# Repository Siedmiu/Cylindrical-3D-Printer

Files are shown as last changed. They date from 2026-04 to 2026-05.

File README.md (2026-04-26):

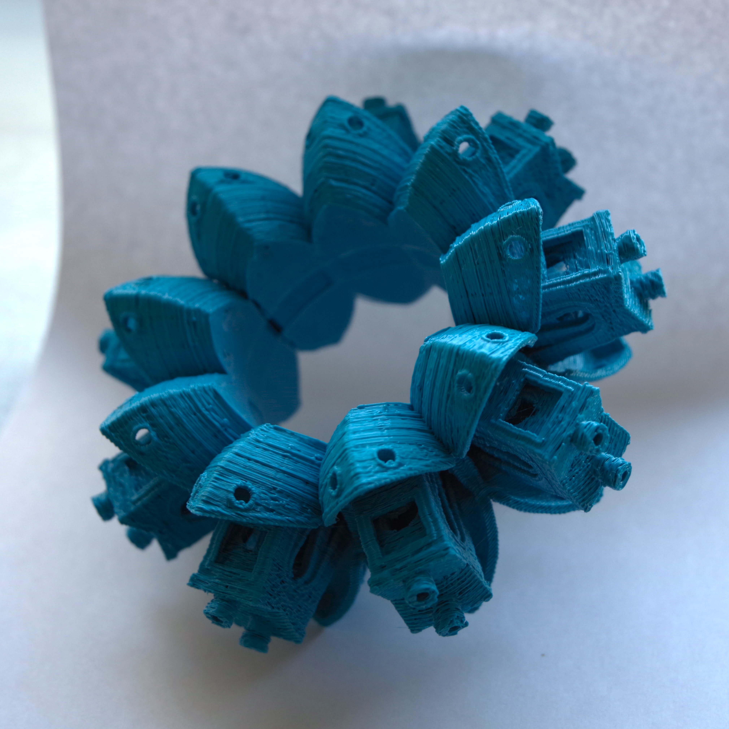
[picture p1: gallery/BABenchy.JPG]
Cylindrical 3D Printer

<sub>Yes, I had a nozzle clog while printing this...</sub>

# Cylindrical 3D Printer

An open-source cylindrical (polar) 3D printer built from raw components and 3D printed parts. Instead of a flat print bed, the model is deposited onto a rotating drum — enabling geometries that are impossible or impractical on a standard Cartesian FDM printer, such as seamless cylindrical shells and radially symmetric structures.

The printer runs **Marlin 2.1** with POLAR kinematics on a **BTT SKR V1.4 Turbo** board. Two independent methods for generating G-code are provided: a slicer-based workflow using Cura with geometric pre/post-processing, and a fully algorithmic approach using a [custom fork of FullControl XYZ](https://github.com/Siedmiu/fullcontrol_Cylindrical).

> **This project is no longer actively developed.** The repository is open for anyone to build on — contributions, forks, and pull requests are very welcome. Happy to answer questions via GitHub Issues.

---

## Gallery

A 3DBenchy printed on the cylindrical printer. The model was adapted to wrap around the drum surface and sliced using the Cura-based workflow.

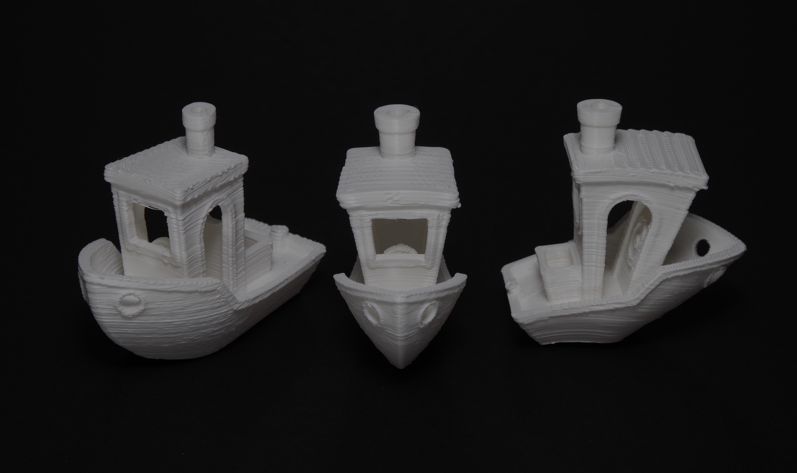
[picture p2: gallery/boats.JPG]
Three Benchys showing cylindrical distortion

*Three 3DBenchy prints: one with corrected distortion and two with different axes of cylindrical distortion, illustrating the effect of the coordinate transformation.*

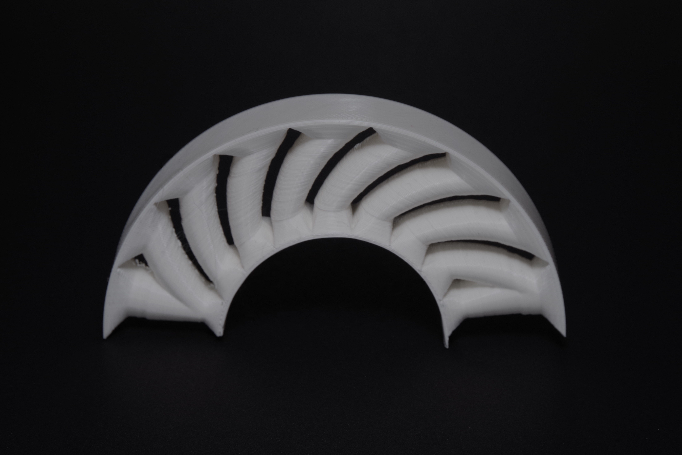
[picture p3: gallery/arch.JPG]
Arch — geometry impossible on standard FDM

*An arch printed directly on the drum — a geometry that cannot be printed without supports on a standard FDM printer, printed here support-free by leveraging the cylindrical build surface.*

### First Print Timelapse

First print timelapse (https://youtu.be/GyanHS4cnVg)

---

## Repository Structure

### [`Marlin config/`](Marlin%20config/)
Marlin 2.1.2.5 firmware configuration for BTT SKR V1.4 Turbo with TMC2208 drivers and POLAR kinematics. Includes a full README with a table of all key changes from stock defaults.

### [`Cura Slicer to cylindrical conversion/`](Cura%20Slicer%20to%20cylindrical%20conversion/)
The primary recommended G-code generation method. A full workflow README describes each step:
1. Prepare and cut the model to fit the drum
2. Flatten the STL from cylindrical to Cartesian geometry (`cylindrical_to_cartesian.py`)
3. Slice in Cura using the included **Custom Cylindrical** printer profile
4. Correct extrusion values for arc paths (`recalculate_extrusion.py`)

Sample files for each step and a propeller example (geometry designed natively for cylindrical printing) are included.

### [`FullcontrollXYZ preview/`](FullcontrollXYZ%20preview/)
An experimental alternative using a [custom fork of FullControl XYZ](https://github.com/Siedmiu/fullcontrol_Cylindrical) to generate toolpaths natively in cylindrical coordinates. Work in progress — the Cura-based method is recommended for most use cases. Includes a rendered preview of results.

### [`Cad Files/`](Cad%20Files/)
STEP file for the complete printer assembly. Compatible with Fusion 360, FreeCAD, SolidWorks, and most other CAD tools.

### [`docs/`](docs/)
Wiring diagram for the BTT SKR V1.4 Turbo board.

### [`diploma/`](diploma/)
Background reading: the original thesis (Polish) with an English translation and an AI-generated abstract covering the design decisions, kinematics, and path generation methods in depth.

### [`gallery/`](gallery/)
Photos and a timelapse of the printer and its prints.

---

## License

[GPL-3.0](LICENSE)

---

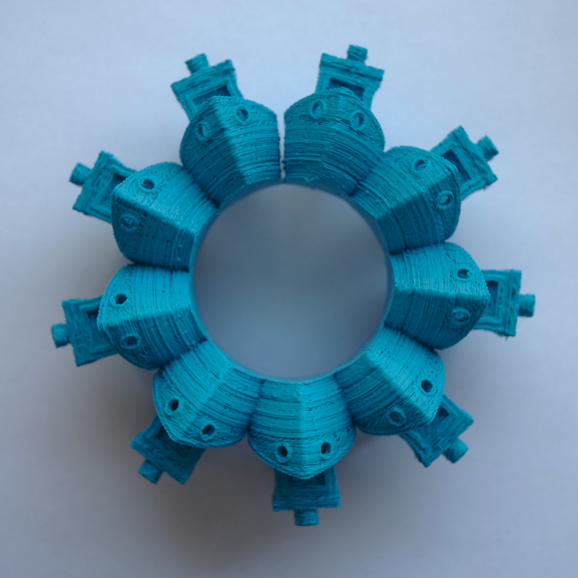
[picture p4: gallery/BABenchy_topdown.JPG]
Cylindrical 3D Printer — top down view


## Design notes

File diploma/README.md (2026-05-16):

# Diploma Thesis

Contains the diploma thesis for this project with useful background on the design and implementation of the cylindrical 3D printer.

Written to university specification under strict time constraints, expect some filler sections.

The plots and figures will not load in github preview!

## Files

| File | Description |
|---|---|
| [Projekt i implementacja cylindrycznej drukarki 3D.pdf](Projekt%20i%20implementacja%20cylindrycznej%20drukarki%203D.pdf) | Original thesis (Polish) |
| [Design and Implementation of a Cylindrical 3D Printer.pdf](Design%20and%20Implementation%20of%20a%20Cylindrical%203D%20Printer.pdf) | Translation by Gemini 3.1 Pro Preview |
| [Diploma_Abstract.md](Diploma_Abstract.md) | AI-generated abstract |

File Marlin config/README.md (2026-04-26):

# Marlin Configuration

[Marlin 2.1.2.5](https://github.com/MarlinFirmware/Marlin/releases) configuration for the cylindrical 3D printer, based on a **BTT SKR V1.4 Turbo** board with **TMC2208** drivers. Uses Marlin's built-in **POLAR** kinematics mode to handle the cylindrical (X-linear + Y-rotational) axis layout.

Built with the [PlatformIO](https://marlinfw.org/docs/basics/auto_build_marlin.html) extension for VS Code. Example configurations for other boards can be found in the [MarlinFirmware/Configurations](https://github.com/MarlinFirmware/Configurations) repository.

## Key Changes from Stock

### `Configuration.h`

| Setting | Custom Value | Stock Default |
|---|---|---|
| `MOTHERBOARD` | `BOARD_BTT_SKR_V1_4_TURBO` | RAMPS/other |
| `SERIAL_PORT` | `-1` (USB) | `0` |
| `X/Y/Z/E0_DRIVER_TYPE` | `TMC2208` | `A4988` |
| `POLAR` | enabled | disabled |
| `PRINTABLE_RADIUS` | `153.0` | — |
| `POLAR_FAST_RADIUS` | `3.0` | — |
| `POLAR_CENTER_OFFSET` | `0.0` | — |
| `FEEDRATE_SCALING` | enabled | disabled |
| `DEFAULT_AXIS_STEPS_PER_UNIT` | `{ 40, 71.50, 200, 72 }` | `{ 80, 80, 400, 500 }` |
| `TEMP_SENSOR_0` | `1` (Ender 3 V2 NTC) | `0` (disabled) |
| `X_BED_SIZE` / `Y_BED_SIZE` | `153` / `360` | `200` / `200` |
| `Y_MIN_POS` / `Y_MAX_POS` | `±999999` (unlimited rotation) | `0` / `200` |

The POLAR kinematics mode treats X as linear radial travel and Y as rotation in degrees. Y limits are set to ±999999 to allow unlimited rotation without endstop triggering.

### `Configuration_adv.h`

TMC2208 StealthChop enabled on all axes:
- `STEALTHCHOP_XY`, `STEALTHCHOP_Z`, `STEALTHCHOP_E` — all enabled
- Motor current: 800 mA on all axes

## Files

| File | Description |
|---|---|
| [Marlin-2.1.2.5/Marlin/Configuration.h](Marlin-2.1.2.5/Marlin/Configuration.h) | Primary machine configuration |
| [Marlin-2.1.2.5/Marlin/Configuration_adv.h](Marlin-2.1.2.5/Marlin/Configuration_adv.h) | Advanced configuration (TMC drivers) |

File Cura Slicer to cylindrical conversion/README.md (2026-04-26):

# Cura Slicer to Cylindrical Conversion

Method for generating G-code for a cylindrical 3D printer using a standard slicer. Works by geometrically flattening a model designed for a cylinder into a Cartesian STL that any slicer can handle, then correcting the extrusion values in post-processing.

> **Note:** This is a working but imperfect method. Dimensional accuracy is good, but there is no topological continuity for fully rotational objects. The [FullControl-based approach](../FullcontrollXYZ%20preview/) generates paths natively in cylindrical coordinates and may be preferable for some geometries.

---

## Workflow

### Step 1 — Prepare the model

Start with a standard 3D model. Cut or adapt it so it can be placed on the surface of the cylinder (drum). The model's geometry should be wrapped around the drum radius before the next step.

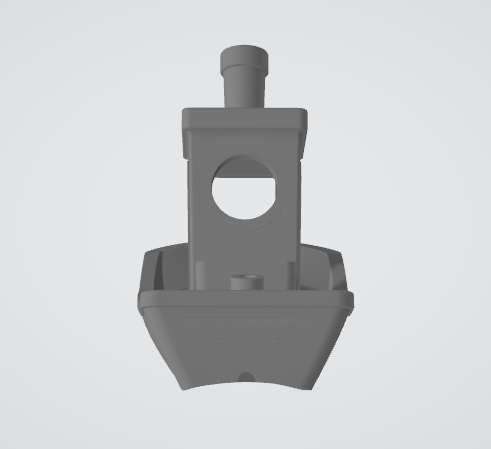
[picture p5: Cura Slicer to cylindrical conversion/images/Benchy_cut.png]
Original model


### Step 2 — Flatten the STL

Run `cylindrical_to_cartesian.py` to unroll the cylindrical geometry into a flat Cartesian STL that a standard slicer can process:

```bash
python cylindrical_to_cartesian.py <input.stl> [output.stl] [drum_radius_mm] [cut_angle_deg]
```

| Parameter | Default | Description |
|---|---|---|
| `drum_radius_mm` | 28.5 (57 mm diameter) | Radius of the print drum |
| `cut_angle_deg` | 180° | Where the seam is placed (0° = +Z, 180° = −Z) |

The output STL can be very large due to triangle subdivision — the sample file includes a `_flattened_decimated.stl` version decimated in Blender to reduce file size. Use the non-decimated version for actual slicing.

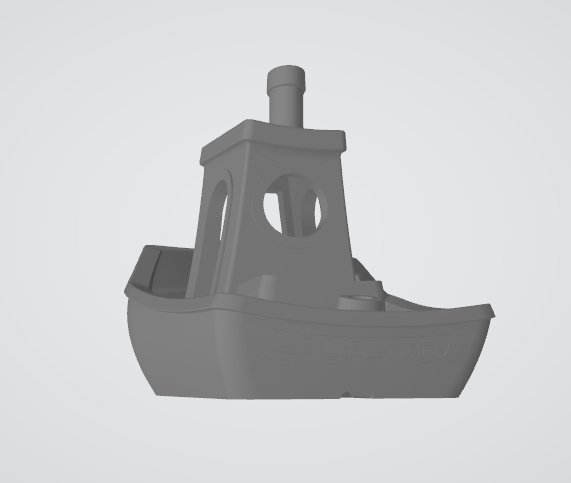
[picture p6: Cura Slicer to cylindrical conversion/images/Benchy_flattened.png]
Flattened model


### Step 3 — Slice in Cura

Import the flattened STL into Cura using the **Custom Cylindrical** printer profile from the [cura_profile](cura_profile/) folder.

To install the profile: copy the contents of `cura_profile/` into your Cura user data directory:
- Windows: `%AppData%\Roaming\cura\<version>\`

The profile sets:
- Build volume: 150 × 361 × 100 mm (X: linear travel, Y: rotation in degrees, Z: height)
- Start G-code with homing, Y-axis zero reset, and a purge line
- End G-code with Z lift and motor disable

Slice normally. Export the `.gcode` file.

### Step 4 — Recalculate extrusion

The slicer calculates extrusion based on flat Cartesian distances. Since the actual print path follows an arc, extrusion must be corrected:

```bash
python recalculate_extrusion.py <input.gcode> [output.gcode] [drum_radius_mm]
```

| Parameter | Default | Description |
|---|---|---|
| `drum_radius_mm` | 28 (56 mm diameter) | Radius of the print drum — **must match Step 2** |

> Make sure `drum_radius_mm` is consistent between both scripts.

The script outputs a `_corrected.gcode` file with adjusted extrusion values. Send this file to the printer.

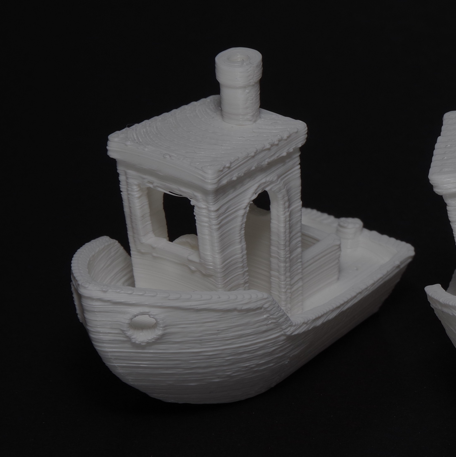
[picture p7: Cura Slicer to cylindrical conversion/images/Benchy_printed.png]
Printed result


The printed Benchy is functionally equivalent to one printed on a standard FDM printer. The main differences are a rounded bottom (conforming to the drum surface instead of sitting flat) and radial bridges, which may exhibit more sagging than on a flat-bed printer. Print quality is lower than a standard printer as this is a prototype, though the result is fully functional.

This example highlights the limitations of adapting flat-bed models to cylindrical printing. To fully leverage this geometry, models should be designed specifically for cylindrical printing — eliminating the rounded-bottom and bridge issues entirely. It is also possible to print unmodified files directly without the flattening step, as shown in the propeller example below.

### Propeller — geometry designed for cylindrical printing

The propeller was designed with cylindrical printing in mind and printed directly without adaptation. This avoids the compromises seen in the Benchy example.

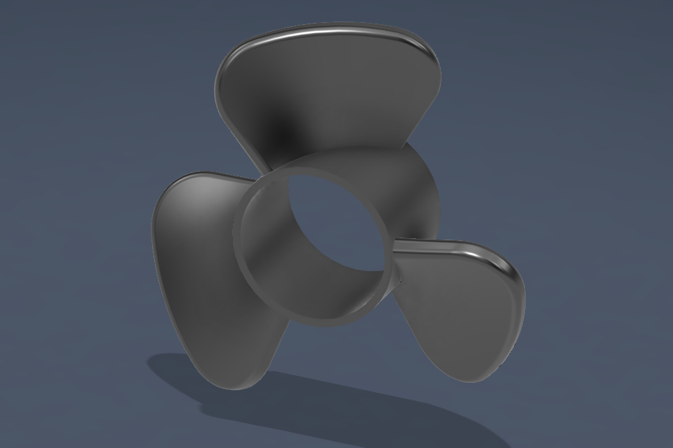
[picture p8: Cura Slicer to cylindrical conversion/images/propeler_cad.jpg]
Propeller CAD


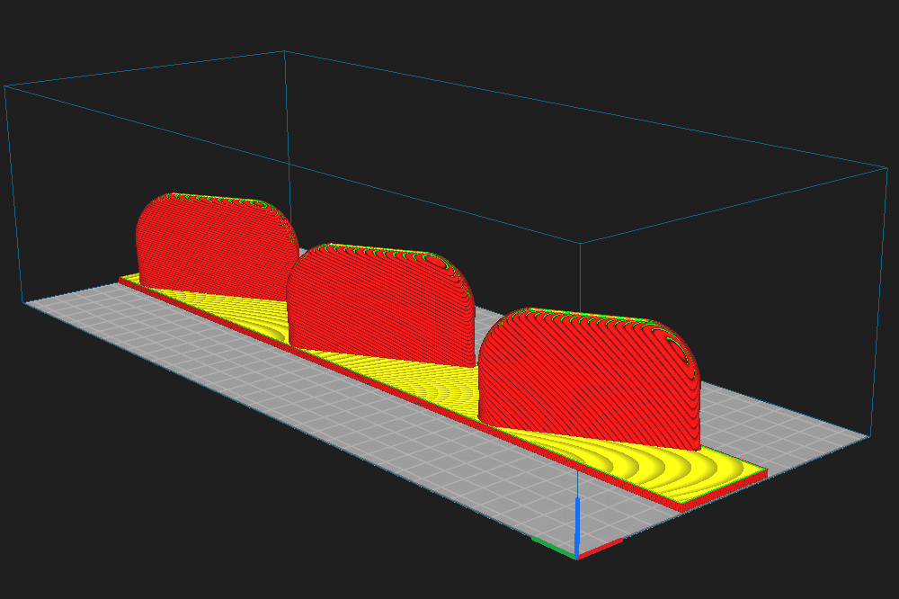
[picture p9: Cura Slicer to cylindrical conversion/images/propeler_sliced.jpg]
Propeller sliced


Propeller printed

---

## Files

| File / Folder | Description |
|---|---|
| [cylindrical_to_cartesian.py](cylindrical_to_cartesian.py) | Flattens cylindrical STL to Cartesian |
| [recalculate_extrusion.py](recalculate_extrusion.py) | Corrects extrusion in sliced G-code |
| [cura_profile/](cura_profile/) | Cura printer profile for Custom Cylindrical |
| [sample gcode/](sample%20gcode/) | Sample files for each step of the workflow |

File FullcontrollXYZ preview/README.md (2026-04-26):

# FullcontrollXYZ Preview

Preview of a forked [FullControl XYZ](https://github.com/Siedmiu/fullcontrol_Cylindrical) adapted to generate toolpaths for a cylindrical 3D printer.

> **Work in progress.** This path-generation method is experimental. Using a slicer recalculation method is recommended over this approach.

## Requirements

The notebooks require:
- The [FullControl XYZ](https://github.com/fullcontrolxyz/fullcontrol) package
- Additional functions for cylindrical printers
All of this is available in the [fork repository](https://github.com/Siedmiu/fullcontrol_Cylindrical)

## Contents

- [cylindrical_printer_tutorial.ipynb](cylindrical_printer_tutorial.ipynb) — tutorial notebook walking through cylindrical path generation
- [cylindrical_printer_tutorial.md](cylindrical_printer_tutorial.md) — rendered preview of tutorial results
- [cylindrical_slicer.ipynb](cylindrical_slicer.ipynb) — slicer notebook; best used with simpler STL files as it is prone to errors and can take a long time to run

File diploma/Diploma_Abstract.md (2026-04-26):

# Chapter 5: Literature Review Abstract

This chapter evaluates the current state of FDM 3D printing, focusing specifically on the limitations of traditional Cartesian architectures and the emergent potential of non-planar, particularly cylindrical, printing technologies. The review identifies key geometric and mechanical constraints in conventional FDM, such as the obligatory reliance on support structures for complex or overhanging geometries, which prolongs manufacturing time, increases material waste, and introduces pronounced mechanical anisotropy due to weak interlayer adhesion. 

To bypass these challenges, research towards non-planar printing proposes utilizing printers with non-Cartesian architectures or increased degrees of freedom (DOF). Cylindrical printers, representing a simple yet effective modification of replacing the linear y-axis with a rotary drum, offer the ability to produce support-free geometries like propellers, spiral constructs, and turning-like parts. The chapter highlights the particular relevance of this technology to the bioprinting sector, where radially outward, layer-by-layer printing prevents the structural collapse of fragile tubular tissues (such as blood vessels) and stents.

Despite successful prototypes introduced over the past decade, the broader adoption of additive lathe (AL) technology is obstructed by a significant research gap: the absence of comprehensive slicing software capable of planning full tool paths for curved surfaces. To date, researchers have had to rely on cumbersome workarounds or proprietary adaptations with heavy geometric limitations. The review also touches on the mechanical necessity of dedicated drive reductions for rotary axes to prevent vertical fine artifacts (VFAs) and maintain positional resolution in cylindrical configurations.

This chapter introduces the motivation and context for developing a cylindrical 3D printer, highlighting the evolution of FDM (Fused Deposition Modeling) technology from rapid prototyping to mature additive manufacturing. The primary goal of the thesis is to design and build a standalone cylindrical 3D printer prototype from scratch, moving away from conventional Cartesian adaptations to fully leverage cylindrical geometry. Along with the mechanical construction, the research focuses on developing specialized toolpath planning algorithms.

The scope of the project purposefully relies on accessible, open-source rep-rap components and FDM-printable parts to ensure reproducibility. While acknowledging certain limitations like the lack of a closed-loop feedback or a dedicated HMI, the prototype serves to demonstrate manufacturing capabilities unattainable on standard Cartesian printers. Finally, the chapter outlines the structure of the thesis, detailing the progression from literature review and mathematical foundations to system architecture, design principles, and slicing algorithm development.

# Abstract: Mathematical Foundations

This chapter explores the mathematical basis required for integrating a cylindrical coordinate system into the additive manufacturing (FDM) design and toolpath generation process. It details the transformation equations between Cartesian and cylindrical coordinates and their corresponding Jacobian matrix to understand geometrical scaling. Furthermore, it extensively analyzes the technical challenges of cylindrical printingâ€”specifically angular resolution and position accuracy propagation. Through calculations of positioning errors and microstepping reduction variables, the chapter concludes that achieving adequate precision on larger working radii necessitates a specific minimum mechanical gear ratio (total ratio $\ge$ 64) for the rotary axis in additive lathe-printers.

# Chapter 3 Abstract: System Design and Architecture

This chapter details the mechanical, kinematic, electronic, and software design of the cylindrical 3D printer prototype (AL). 

- **Mechanical Design**: The structure relies on cost-effective, open-source compatible aluminum extrusions and 3D-printed components. A key material choice included PC/ABS for heat-adjacent parts due to its thermal resistance, alongside PLA for other structural components.
- **Kinematics**: The system adapts a standard Cartesian framework into polar kinematics by replacing the transverse linear Y-axis with a continuous rotary drum. To achieve high angular resolution while minimizing mechanical backlash, various reduction mechanisms were tested, culminating in a successful two-stage belt drive offering a 16:1 gear ratio. A custom printhead was also designed to adjust the nozzle's alignment with the drum's rotary axis.
- **Electronics & Control**: The printer is powered by a 32-bit BTT SKR V1.4 Turbo board paired with TMC2208 stepper drivers operating in UART and StealthChop modes. Temperature regulation is handled via a PID-controlled cartridge heater and NTC 100k thermistor.
- **Marlin Firmware Implementation**: The open-source Marlin firmware was customized to interpret polar coordinates by enabling the POLAR module. Adjustments included removing mechanical homing limits for the continuous rotary axis, remapping hardware pins for appropriate fan control, and executing calibration procedures to fine-tune steps per unit and PID thermal parameters for optimal performance.

# Abstract: Manufacturing Capabilities and Applications

This chapter explores the manufacturing capabilities and constraints associated with Forward Deposition Modeling (FDM) technology, centering around Design for Additive Manufacturing (DfAM) principles. Initially, it examines Cartesian 3D printing, evaluating how critical parameters like build orientation, raster angle, layer thickness, and infill impact the structural strength, mechanical durability, and surface texture of printed parts. Limitations such as weak interlayer bonds and the necessity of support structures for overhanging geometries are also addressed.

The chapter then extends these DfAM principles to cylindrical 3D printing, detailing its operational paradigm and radial manufacturing direction. It highlights unique challenges, such as the potential for delamination when depositing parallel helical paths, and introduces pattern arrangements like face-centered cubic (FCC) lattices to mitigate these structural weaknesses.

Finally, the text underscores the distinct geometric advantages of cylindrical 3D printing over traditional Cartesian methods. Key benefits include the continuity of rotation for seamless structural properties, the capability to manufacture complex internal geometries layer by layer, and most notably, the ability to eliminate support structures for complex overhangs—exemplified by a propeller design—thereby drastically reducing printing times and material consumption.

# Chapter 5: Path Generation

This chapter explores various methods for generating tool paths for cylindrical 3D printers. It first examines the application of existing Cartesian slicers, proposing a geometry transformation algorithm that compensates for cylindrical distortions alongside a script for recalculating extrusion parameters. This approach yields good dimensional accuracy but lacks topological continuity for fully rotational objects. An alternative methodology using algorithmic G-code generation via FullControl Designer is discussed, focusing on its ability to produce complex parametric paths natively in cylindrical coordinates without the discontinuities created by traditional slicers. A custom cylindrical slicer implemented within FullControl, inspired by recent research, is also presented; it extracts print contours directly onto concentric cylindrical layers. Although the custom slicer successfully mapped paths with rectilinear infill for simple geometries, it faced computational bottlenecks and contour generation errors when processing highly complex models. The chapter suggests further optimizations in contour extraction as a vital future step.

# Chapter 6: Results and Discussion - Abstract

This chapter summarizes the results and discussion concerning the design and toolpath generation for a cylindrical printer. It highlights the success of mechanical reduction and belt drives in achieving optimal resolution. The adaptation of the Marlin software for polar kinematics via the POLAR module proved successful, identifying a need for bed-to-nozzle calibration and a drum centering mechanism. The chapter also evaluates three toolpath generation methods: mapping Cartesian slices (best for complex shapes but lacks continuous rotation), expanding the FullControl GCode Designer (offers full control but is tedious for each segment), and a dedicated prototype cylindrical slicer (optimal mechanically but struggles with complex geometry). Finally, it outlines future development directions, emphasizing the critical need for robust contour extraction, advanced partial infill strategies accounting for cylindrical curvature, and modern print optimizations like pressure control and input shaping.

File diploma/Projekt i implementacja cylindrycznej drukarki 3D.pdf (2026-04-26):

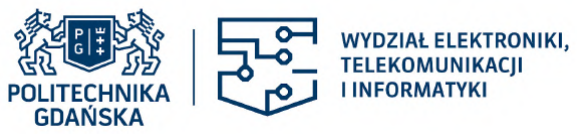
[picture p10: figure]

Imię i nazwisko studenta: Grzegorz Lange
Nr albumu: 190906
Poziom kształcenia: studia pierwszego stopnia
Forma studiów: stacjonarne
Kierunek studiów: Automatyka, cybernetyka i robotyka Profil: Systemy decyzyjne i robotyka

### PROJEKT DYPLOMOWY INŻYNIERSKI

Tytuł projektu w języku polskim: Projekt i implementacja cylindrycznej drukarki 3D

Tytuł projektu w języku angielskim: Design and Implementation of a Custom Cylindrical 3D Printer

Opiekun pracy: dr inż. Piotr Fiertek

### STRESZCZENIE

Praca przedstawia prototyp cylindrycznej drukarki FDM wraz z opracowaniem metodologii generacji scie ´ zek narzędzia dla kinematyki walcowej. Specyficzna kinematyka cylindryczna rozszerza ˙ wachlarz geometrii dostępnych dla kartezjanskiego druku 3D o komponenty o symetrii obroto- ´

wej, struktury helikalne oraz wytwory o charakterze tokarskim z wewnętrzn ą geometri ą. Walcowy układ współrzędnych pozwala na orientację narzędzia, eliminuj ąc ą potrzebę zastosowania struktur podporowych dla szerokiej gamy elementów. Wielokrotny obrót bębna roboczego pozwala
zachowanie ci ągłosci trajektorii ekstruzji wzdłu ´ | z osi obrotowej, co prowadzi do wła ˙ | sciwo ´ | sci mate- ´

riału zblizonych do izotropowych. ˙
Praca przedstawia trzy podejscia do generacji ´ | scie ´ | zek: adaptację istniej ących ˙ | slicerów
kartezjanskich z matematyczn ą korekcj ą zniekształce ´ | n geometrycznych oraz parametrów ekstru- ´
zji, rozszerzenie srodowiska FullControl GCode Designer umo ´ | zliwiaj ące bezpo ˙ | sredni ą generację ´

prostych geometrii opisanych funkcjami matematycznymi, prototypow ą implementację slicera cy-
lindrycznego, umozliwiaj ącego generacje ˙ | scie ´ | zek narzędzia na podstawie modeli STL, z uwzględ- ˙
nieniem parametrów obwodowych scian i wypełnienia prostoliniowego. Testy prototypu potwier- ´
dziły wykonalnosć sprę ´ | zyn, ˙ | srób oraz innych geometrii obrotowych bez konieczno ´ | sci stosowania ´

struktur podporowych.

Słowa kluczowe: drukarka cylindryczna, wytwarzanie przyrostowe, generacja scie ´ zek narzędzia, ˙

eliminacja struktur podporowych
Dziedzina nauki i techniki: Inzynieria mechaniczna, Automatyka i robotyka ˙

### ABSTRACT

This work presents a cylindrical FDM printer prototype along with tool path generation methodology for cylindrical kinematics. Cylindrical kinematics expands the range of geometries available for Cartesian 3D printing to include rotationally symmetric components, helical structures, and lathe-like products with internal geometry. The cylindrical coordinate system allows for tool orientation that eliminates the need for support structures for a wide range of components. Continuous rotation of the working drum enables continuity of extrusion trajectories along the rotational axis, leading to material properties approaching isotropic behavior.
This work presents three approaches to path generation: adaptation of existing Cartesian slicers with mathematical correction of geometric distortions and extrusion parameters; extension of the FullControl GCode Designer environment enabling direct generation of simple geometries described by mathematical functions; prototype implementation of a cylindrical slicer enabling tool path generation from STL models, incorporating perimeter wall parameters and rectilinear infill. Prototype tests confirmed the feasibility of springs, screws, and other rotational geometries without the need for support structures.

Keywords: cylindrical printer, additive manufacturing, tool path generation, support structure elimination
Field of science and technology: Mechanical Engineering, Automation and Robotics

### SPIS TRESCI ´

STRESZCZENIE | 3
ABSTRACT | 4
SPIS TRESCI ´ | 6
WYKAZ WAZNIEJSZYCH OZNACZE ˙ | N I SKRÓTÓW | 7 ´
1 WST ĘP | 9
2 PRZEGL ĄD LITERATURY | 12
3 PODSTAWY MATEMATYCZNE | 15
3.1.3 Planowanie scie ´ | zek walcowych w AM | ˙ | 17
3.2.1 Analiza rozdzielczosci i dokładno ´ | sci pozycji | ´ | 18
4 PROJEKT I ARCHITEKTURA SYSTEMU | | 22
4.3.1 Konfiguracja poł ączen elektrycznych | ´ | 29

5 MOZLIWO ˙ | SCI WYTWÓRCZE I ZASTOSOWANIA | 33 ´
5.0.1 DfAM w kartezjanskim druku 3D | ´ | 33
5.1.1 Ci ągłosć obrotu | ´ | 37
6 GENERACJA SCIE ´ | ZEK | 40 ˙
6.1 Zastosowanie slicerów kartezjanskich | ´ | 40
6.1.2 Rozwi ązania ograniczen | ´ | 42
6.1.4 Wnioski z zastosowania slicerów kartezjanskich | ´ | 46
6.3.1 Implementacja slicera w srodowisku FullControl | ´ | 50
7 WYNIKI I DYSKUSJA | 53
7.2 Generacja scie ´ | zek narzędzia | ˙ | 53
SPIS RYSUNKÓW | 55
SPIS TABEL | 56
BIBLIOGRAFIA | 59

WYKAZ WAZNIEJSZYCH OZNACZE ˙ | N I SKRÓTÓW ´
ABS | – ang. acrylonitrile butadiene styrene – akrylonitrylo-butadieno-styren
AL | – ang. additive lathe – tokarko-drukarka przyrostowa
AM | – ang. additive manufacturing – wytwarzanie przyrostowe
CAD | – ang. computer aided design – projektowanie wspomagane komputerowo
CNC | – ang. computer numerical control – sterowanie numeryczne
DfAM | – ang. Design for Additive Manufacturing – projektowanie pod wytwarzanie przyro-
stowe
DOF | – ang. degrees of freedom – stopnie swobody
FDM | – ang. fused deposition modeling – osadzanie topionego materiału
HMI | – ang. Human Machine Interface – interfejs człowiek-maszyna
PC | – ang. polycarbonate – poliwęglan
PCL | – ang. polycaprolactone – polikaprolakton
PID | – ang. Proportional-Integral-Derivative controller – regulator proporcjonalno-całkuj ąco-
rózniczkuj ący ˙
PLA | – ang. polylactic acid – kwas polilaktydowy
PWM | – ang. Pulse Width Modulation – modulacja szerokosci impulsów ´
SLA | – ang. stereolithography – stereolitografia
SLS | – ang. selective laser sintering – selektywne spiekanie laserowe
STL | – ang. STereoLithography – format pliku siatki trójk ątów
VFA | – ang. vertical fine artifacts – pionowe artefakty drobne

Oznaczenia wazniejszych symboli ˙

A | – pole powierzchni [mm²
]
de | – odległosć euklidesowa [mm] ´
E | – wartosć parametru ekstruzji w G-code [mm] ´
ℎl | – grubosć warstwy radialnej [mm] ´
ig | – przełozenie przekładni mechanicznej ˙
I | – intensywnosć pokrycia powierzchni ´

J – macierz Jakobianu transformacji współrzędnych

Kp, Ki

, Kd – parametry regulatora PID (proporcjonalny, całkuj ący, rózniczkuj ący) ˙

l | – długosć odcinka [mm] ´
r | – promien lub odległo ´ | sć punktu od osi obrotu w układzie cylindrycznym [mm] ´
rd | – promien bębna roboczego drukarki cylindrycznej [mm] ´
ri | – promien´ i-tej warstwy cylindrycznej [mm]
s | – długosć łuku na powierzchni cylindra [mm] ´
Tg | – temperatura zeszklenia materiału [°C]
Tm | – temperatura topnienia materiału [°C]
Tn | – temperatura dyszy ekstrudera [°C]
V | – objętosć [mm ´

3
| | ]
w | – szerokosć´ scie ´ | zki ekstruzji [mm] ˙
x, y, z | – współrzędne kartezjanskie punktu [mm] ´
θ | – k ąt nachylenia promienia w układzie cylindrycznym [°]
σx, σy, σz – niepewnosć pozycjonowania w osiach kartezja ´ | nskich [mm] ´

σr , σθ , σℎ – niepewnosć pozycjonowania w osiach cylindrycznych [mm, rad, mm] ´

### 1. WST ĘP

Szeroka dostępnosć i niski próg wej ´ | scia, kontrastuj ące z wachlarzem mo ´ | zliwo ˙ | sci jakie oferuje ´
technologia druku trójwymiarowego, przyci ągnęły hobbystów, inzynierów i artystów z całego ˙ | swiata. ´

Narodziny, rozkwit i dojrzewanie wytwarzania przyrostowego zasilane kooperacj ą ludzi działaj ących dla dobra całej społecznosci przerodziło się w ekosystem wzajemnej inspiracji i otwartego ´ dzielenia się wiedz ą, gdzie nauka, inzynieria i sztuka współistniej ą i wzajemnie się napędzaj ą. ˙

### 1.1. Rozwój technologii FDM

Osadzanie topionego materiału (FDM, ang. fused deposition modeling) jest najpopularniejszym z procesów wytwarzania przyrostowego (AM, ang. additive manufacturing). Technologia FDM
doswiadczyła gwałtownego rozwoju po demokratyzacji w 2009 roku, wraz z wyga ´ | snięciem patentu ´
firmy Stratasys [1] z 1988 roku. Istota procesu FDM polega na starannym, warstwowym osadzaniu uplastycznionego termoplastiku az do utworzenia nowego obiektu. Materiał dostarczany jest za ˙ pomoc ą ekstrudera i dystrybułowany z dyszy, której dokładne pozycjonowanie zapewnia maszyna sterowana numerycznie (CNC, ang. computer numerical control).

W pocz ątkowej fazie rozwoju, innowacyjna technologia produkcji, jak ą była technologia FDM, postrzegana była przede wszystkim jako narzędzie wspomagaj ące szybkie prototypowanie, nie zas jako samodzielna metoda wytwarzania dóbr. Dekada 2010–2020 charakteryzowała ´

się dynamicznym postępem technicznym technologii FDM i rozwojem rynku, przy czym znacz ąc ą
częsć kontrybucji przypisuje się społeczno ´ | sci ´ | open source. Aktualnie, w chwili dojrzałosci tech- ´
nicznej maszyn drukuj ących i stopniu zaawansowania materiałów produkcyjnych, o rzeczywistej
uzyteczno ˙ | sci technologii FDM w procesach wytwórczych decyduje przede wszystkim rozwój me- ´

todologii projektowania dedykowanej wytwarzaniu przyrostowemu (DfAM) [2].

### 1.2. Cel i zakres pracy

Głównym celem pracy jest opracowanie prototypu cylindrycznej drukarki 3D, jako niezaleznej ma- ˙
szyny. Szczególn ą uwagę poswięcono tak ´ | ze algorytmom planowania ˙ | scie ´ | zek, w tym warunkom, ˙
jakie musz ą byc spełnione aby w pełni wykorzysta ´ | c zalety geometrii cylindrycznej. ´
1.2.1. Cele badawcze

Pracę rozpoczęto od analizy literatury technicznej w zakresie istniej ących implementacji drukarek cylindrycznych, w celu identyfikacji optymalnych rozwi ązan fizycznej konstrukcji. Prace projek- ´

towe i implementacje skupiaj ą się na konstrukcji dedykowanej maszyny cylindrycznej, w prze-
ciwienstwie do stosowanego dotychczas w literaturze podej ´ | scia opartego na adaptacji konwen- ´
cjonalnych drukarek kartezjanskich. Projektowanie drukarki od podstaw umo ´ | zliwia optymaliza- ˙

cję architektury systemu pod wymagania specyficzne dla kinematyki cylindrycznej, oraz czyni
rozwi ązanie niezaleznym od zewnętrznych producentów. Ko ˙ | ncowym celem pracy jest fizyczna ´
implementacja maszyny 1.1 oraz wytworzenie prostych wydruków o geometrii niemozliwej do ˙ osi ągnięcia na standardowych drukarkach kartezjanskich. Implementacja ma za zadanie wska- ´
zac kierunek rozwoju technologii oraz zidentyfikowa ´ | c potencjalne problemy systemu w warunkach ´

rzeczywistych.

1.2.2. Zakres i ograniczenia pracy
Ograniczenie zakresu pracy ma na celu zapewnienie osi ągalnosci i reprodukowalno ´ | sci projektu. ´
Przyjęte ograniczenia dotycz ą materiałów konstrukcyjnych, komponentów elektronicznych i za-
kresu funkcjonalnosci prototypu. W pracy starano się wykorzysta ´ | c dostępne rozwi ązania ´ | open

source oraz komponenty rozpowszechnione w drukarkach typu RepRap lub ich komercyjnych odpowiednikach. Elementy konstrukcyjne projektowano tak, aby umozliwi ˙ c ich wyprodukowanie ´

za pomoc ą standardowej drukarki 3D typu FDM, bez potrzeby stosowania zaawansowanych narzędzi lub wyposazenia. ˙

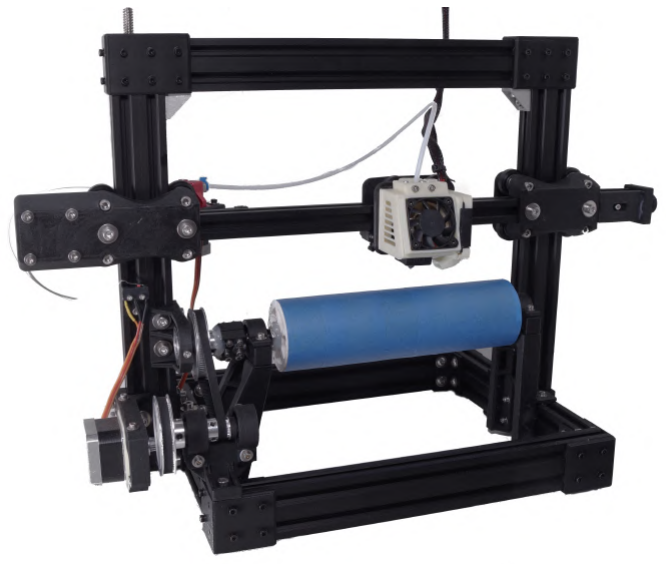
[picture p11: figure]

Rysunek 1.1: Zdjęcie implementacji fizycznej drukarki cylindrycznej wykonanej w ramach projektu

Prototyp stworzonej drukarki cylindrycznej 1.1 pomija szereg funkcji, które byłyby niezbędne w pełni funkcjonalnej maszynie. Do pominiętych funkcji nalez ą: brak systemu poziomo- ˙ wania powierzchni roboczej; brak dedykowanego interfejsu człowiek–maszyna (HMI, ang. Human
Machine Interface); brak zamkniętej pętli sprzęzenia zwrotnego dla kontroli poło ˙ | zenia k ątowego ˙
bębna. Sterowanie w pętli otwartej z silnikiem krokowym moze prowadzi ˙ | c do akumulacji błędów ´
pozycjonowania przy długotrwałych procesach, wymagaj ących wielu obrotów bębna lub duzych ˙ momentach bezwładnosci wydruku. ´
1.2.3. Organizacja pracy

Rozdział "Przegl ąd literatury" poswięcony jest dokładnej analizie stanu technicznego konstruk- ´ cji mechanicznych drukarek cylindrycznych i algorytmów generacji scie ´ zek narzędzia. Opisano ˙ przykłady konstrukcji mechanicznych na podstawie których planowano prototyp implementacji fi-
zycznej, podejscia do generacji ´ | scie ´ | zek oraz zastosowania drukarek cylindrycznych. ˙

W rozdziale "Podstawy matematyczne" przedstawiono fundamentalne koncepcje mate-
matyczne na których oparto algorytmy generacji scie ´ | zek druku cylindrycznego. Wykonano tak ˙ | ze˙
analizę rozdzielczosci i dokładno ´ | sci pozycjonowania w układzie walcowym, na podstawie której ´
okreslono wymagane specyfikacje prototypu drukarki cylindrycznej. ´

W rozdziale "Projekt i architektura systemu" opisano proces projektowania oraz implementacji fizycznego prototypu cylindrycznej drukarki 3D. Omówiono w nim architekturę mechaniczn ą maszyny, dobór komponentów elektronicznych oraz rozwi ązania konstrukcyjne zapewniaj ące wymagan ą rozdzielczosć pozycjonowania. Przedstawiono testowane układy redukcji mecha- ´

nicznej napędu obrotowego, systemu napędu osi liniowych, elektronikę, system sterowania oraz adaptacje oprogramowania Marlin.
W rozdziale "Mozliwo ˙ | sci wytwórcze i zastosowania" przedstawiono analizę zasad pro- ´
jektowania dla wytwarzania przyrostowego w kontekscie zarówno drukarek kartezja ´ | nskich, jak ´
i cylindrycznych. Pierwsza częsć rozdziału zawiera przedstawienie ogranicze ´ | n i dobrych praktyk ´
projektowych w standardowym druku FDM, na których bazuje częsć druga, w której przedsta- ´

wiono unikalne zalety geometryczne druku cylindrycznego.
W rozdziale "Generacja scie ´ | zek narzędzia" przedstawiono metodologię planowania tra- ˙
jektorii dla drukarki cylindrycznej. Omówiono w nim podejscia generowania ´ | scie ´ | zek stosowane ˙
w literaturze przedmiotu, wraz z ich ograniczeniami i mozliwo ˙ | sciami. Bazuj ąc na konceptach ´
omówionych podejsć generacji ´ | scie ´ | zek, zaproponowano nowe rozwi ązania oraz przedstawiono ˙
ich implementacje. Wskazano kierunki dalszego rozwoju technologii algorytmów slicingu dla kinematyki cylindrycznej.

### 2. PRZEGL ĄD LITERATURY

### 2.1. Ograniczenia tradycyjnej technologii FDM

Technologia FDM zmaga się z szeregiem ograniczen, stanowi ących barierę dla zastosowania ´
w wielu gałęziach przemysłu. Większosć z tych barier wywodzi się z ogranicze ´ | n geometrycznych ´
technologii, czasu produkcji oraz często niewystarczaj ących własciwo ´ | sci mechanicznych. ´

Ograniczenia geometryczne i czasowe

Do najwazniejszych ogranicze ˙ | n nale ´ | z ą bariery geometryczne zwi ązane z wytwarzaniem struktur ˙
o nieplanarnej orientacji. Jak zauwazaj ą Zhao i współautorzy [3]: „Tradycyjne drukarki XYZ dosko- ˙ nale radz ą sobie z planarnym cięciem warstw, ale napotykaj ą ograniczenia podczas wytwarzania
struktur niepoziomych, nawisów oraz częsci o zło ´ | zonej geometrii [4–6], które wymagaj ą struktur ˙
podporowych [2], zwiększaj ących zarówno czas, jak i koszty materiałowe produkcji”. Zwiększanie
mocy elementów wykonawczych z pewnosci ą mo ´ | ze przynie ˙ | sć poprawę czasów produkcji, ale jest ´
bezposrednio zwi ązane z wzrostem kosztów i nie adresuje problemów metodologii. Wspomniane ´
struktury podporowe nie s ą integraln ą częsci ą procesu, wynikaj ą z ogranicze ´ | n geometrycznych i ´
braku mozliwo ˙ | sci druku bez wsparcia. ´
Ograniczenia własciwo ´ | sci mechanicznych ´

Obecnie uzywane filamenty, będ ące podstawow ą form ą dostarczania surowego materiału od dy- ˙
szy ekstrudera, charakteryzuj ą się znacz ąco nizsz ą wytrzymało ˙ | sci ą i sztywno ´ | sci ą w porównaniu ´
z ceramikami czy metalami, powszechnie stosowanymi w przemysle. Do gamy dostępnych ma- ´
teriałów nalez ą między innymi polimery, piany i kompozyty, jednak niezale ˙ | znie od wykorzystywa- ˙
nego materiału, proces FDM nie pozwala na osi ągnięcie w pełni izotropowych własciwo ´ | sci me- ´

chanicznych materiału bazowego. Wynika to z natury przyrostowego procesu nakładania warstw i wytłaczania wi ązek materiału. Adhezja międzywarstwowa pozostaje znacz ąco słabsza niz wy- ˙ trzymałosć w kierunku równoległym do ci ągłych linii w obrębie pojedynczej warstwy, co przejawia ´ się jako silna anizotropia własciwo ´ sci mechanicznych wyprodukowanego elementu. ´

2.1.1. Drukowanie nieplanarne
Powyzsze problemy staraj ą się rozwi ąza ˙ | c badania w kierunku technologii drukowania nieplanar- ´
nego (ang. non-planar 3D printing), realizowanego przez drukarki o architekturze niekartezjan-´ skiej lub systemy charakteryzuj ące się zwiększon ą liczb ą stopni swobody DOF (ang. degrees of freedom). Rozwi ązania te pozwalaj ą na eliminację struktur podporowych oraz umozliwienie ˙ orientacji kolejnych warstw materiału zgodnie z przewidywanymi kierunkami propagacji napręze˙ n´ mechanicznych. Druk nieplanarny w teorii pozwala na osi ągnięcie blisko izotropowych własciwo- ´
sci wytrzymało ´ | sciowych, jednak problemem pozostaje optymalne planowanie ´ | scie ´ | zek narzędzia, ˙

oraz komplikacja kinematyki odwrotnej, spowodowana dodawaniem kolejnych stopni swobody ruchu.

2.1.2. Drukarki cylindryczne i ich zastosowania

Prosta kinematyka drukarek cylindrycznych w poł ączeniu z pokryciem szerokiej gamy geometrii,
odmiennych od tych mozliwych do wytworzenia na klasycznych drukarkach FDM, mo ˙ | ze stanowi ˙ | c´
rozwi ązanie problemu, który usiłuj ą rozwi ązac drukarki o zwiększonej liczbie stopni swobody. Kon- ´ strukcja drukarek cylindrycznych modyfikuje kartezjanskie drukarki 3D z karet ą X na podnoszonej ´

osi OZ (ang. cartesian gantry Z-lift) poprzez zast ąpienie ruchomego stołu (ruch liniowy w osi OY), obrotowym bębnem realizuj ącym ruch obrotowy wokół osi OX. Ta prosta zmiana otwiera nowe
mozliwo ˙ | sci wytwarzania geometrii dotychczas trudnych lub niemo ´ | zliwych do realizacji w konwen- ˙
cjonalnych systemach kartezjanskich. Mo ´ | zliwe staje się bezpodporowe drukowanie elementów ˙
takich jak smigła i wirniki, struktur o geometrii spiralnej (sprę ´ | zyny, ˙ | sruby), komponentów o cha- ´

rakterze tokarskim z uwzględnieniem wewnętrznej geometrii, a takze biologicznych struktur tubo- ˙
wych, w tym naczyn krwiono ´ | snych. ´

Zastosowanie technologii drukowania cylindrycznego w kontekscie bioprintingu jest szcze- ´
gólnie poz ądane, poniewa ˙ | z mo ˙ | ze umo ˙ | zliwi ˙ | c tworzenie wytrzymałych konstrukcji biologicznych. ´
Reeser i współautorzy pisz ą [7]: „Kłopotliwym problemem w druku 3D biomateriałów jest kolaps
lub deformacja struktur spowodowana słabymi własciwo ´ | sciami mechanicznymi powszechnych ´
biomateriałów. Moze to by ˙ | c szczególnie problematyczne dla konstrukcji zawieraj ących pustki, ´

zwłaszcza rurowych struktur biologicznych. [. . . ] Tokarko-drukarka dostarcza metodologię do budowania takich struktur radialnie na zewn ątrz po jednej warstwie na raz, w przeciwienstwie do ´
złozonej koordynacji wymaganej dla współdruku biomateriałów o unikalnych wła ˙ | sciwo ´ | sciach, ró ´ | z-˙
nych typów komórek i struktur podporowych”. W poł ączeniu z najnowszymi osi ągnięciami w bio-
printingu, jak na przykład ultra wysok ą rozdzielczosci ą druku linii o szeroko ´ | sci 20 ´ | μm z wykorzy-
staniem tr ąby komara [8], technologia druku 3D otwiera mozliwo ˙ | sci produkcji zaawansowanych ´

struktur organicznych.

### 2.2. Istniej ące implementacje druku cylindrycznego

Pomimo upływu ponad dekady od propozycji pierwszych prototypów, technologia druku cylindrycznego pozostaje niszowym rozwi ązaniem, nieprzekraczaj ącym granicy laboratoriów badawczych. Zespoły badawcze zainteresowane rozwojem tej technologii najczęsciej decyduj ą się na ´
adaptację istniej ących drukarek kartezjanskich. Do dnia dzisiejszego ´ | zaden zespół nie opracował ˙
jeszcze kompletnego oprogramowania do planowania scie ´ | zek procesu wytwarzania. ˙
2.2.1. Przegl ąd rozwoju technologii drukarek cylindrycznych

Pierwszy fizyczny prototyp technologii tokarko-drukarki przyrostowej (AL, ang. additive lathe) został zaprezentowany przez Yoava Stermana w 2011 roku w ramach projektu pt. „The Additive Lathe” [9]. Prototyp ten posiadał liczne ograniczenia mechaniczne, z których najistotniejszym
był brak mozliwo ˙ | sci regulacji odległo ´ | sci między cylindrem a głowic ą drukuj ąc ą. Takie podej ´ | scie ´

uniemozliwiało nakładanie kolejnych warstw materiału. Z topologicznego punktu widzenia była ˙ to jedynie maszyna dwu wymiarowa, operuj ąca na płaszczyźnie walcowej. W 2013 roku Kenich i współpracownicy opracowali pierwszy prototyp umozliwiaj ący ruch w kierunku Z [10]. System ˙ ten, zainspirowany drukark ą open-source RepRap Mendel był pierwsz ą funkcjonaln ą drukark ą AL.

Najnowsze osi ągnięcia w dziedzinie drukowania cylindrycznego zostały przedstawione przez Zhao i współautorów [3], którzy opracowali ekonomiczn ą implementację drukarki rotacyjnej FDM opartej na modyfikacji popularnej drukarki Prusa i3 MK3s. Zadanie układu steruj ącego pełniła płyta główna Duet 2 WIFI oraz oprogramowanie RepRap firmware w wersji 3.1.1. Metodologia planowania procesu opracowana przez Zhao i współautorów opiera się na mapowaniu powierzchniowym i obejmuje dwunastostopniowy algorytm cylindrycznego slicingu. Proces rozpoczyna się od importu modelu 3D w formacie STL, po czym następuje obliczenie osi centralnej modelu i zapewnienie jej współosiowosci z centrum obrotowej platformy roboczej. ´ System generuje współsrodkowe cylindryczne powierzchnie cięcia w kierunku radialnym, które ´ przecinaj ą się z modelem 3D w celu ekstrakcji konturów kazdej zakrzywionej warstwy. Punkty kon- ˙
turów w współrzędnych kartezjanskich ´ | (xc, yc, zc) s ą następnie mapowane na punkty (rc, ℎc, θc)
we współrzędnych cylindrycznych na powierzchni walcowej. Koncowym etapem jest generowanie ´ kodu steruj ącego zgodnego z formatem G-code.
2.2.2. Współczesna implementacja w dziedzinie bioprintingu

W dziedzinie bioprintingu, gdzie słabe własciwo ´ sci mechaniczne powszechnych biomateriałów ´

stanowi ą wyzwanie, drukowanie cylindryczne umozliwia budowanie struktur tubularnych radialnie ˙ na zewn ątrz warstwa po warstwie, eliminuj ąc problem zapadania się konstrukcji pod własnym cięzarem. Firma Sichuan Revotek Co. Ltd. ogłosiła w 2016 roku skuteczn ą implantację biodrukowa- ˙
nych naczyn krwiono ´ | snych trzydziestu małpom Rezus, chocia ´ | z wyniki te nie zostały opublikowane ˙
w czasopismie recenzowanym [11; 12]. ´
Technologia wykazała takze u ˙ | zyteczno ˙ | sć w wytwarzaniu stentów z bioresorbowalnych ´
polimerów. Guerra i współautorzy przeprowadzili systematyczne badania wpływu parametrów
drukowania (temperatura, prędkosć, natę ´ | zenie przepływu materiału) na wła ˙ | sciwo ´ | sci fizyczne sten- ´
tów z PCL [13–15]. Badania zakonczyły się pomy ´ | slnym zastosowaniem pneumatycznych aktuato- ´
rów kompozytowych w dziedzinie robotyki miękkiej.

### 2.3. Analiza luki badawczej

Szersze zastosowanie technologii AL pozostaje utrudnione z powodu braku dostępnego opro-
gramowania do generowania scie ´ | zek narzędzia, zawieraj ącego funkcje współczesnych ˙ | slicerów.
Poszczególne zespoły badawcze opracowały autorskie obejscia tego problemu: Kenich i współ- ´ pracownicy zastosowali platformę Slic3r w niekonwencjonalny sposób, modeluj ąc częsci jako ´
płaskie, co ograniczało złozono ˙ | sć mo ´ | zliwych do wytworzenia geometrii. Coulter i współauto- ˙

rzy zaimplementowali najbardziej zaawansowane rozwi ązanie programistyczne, wykorzystuj ące wtyczkę Grasshopper3D dla oprogramowania Rhino do tworzenia rekonstrukcji zeskanowanych
powierzchni dwukrzywiznowych i generowania scie ´ | zek narzędzia wzdłu ˙ | z tych zakrzywionych po- ˙

wierzchni [16; 17]. Dotychczasowo wykorzystywane rozwi ązania posiadaj ą silne ograniczenia geometryczne lub nie wykorzystuj ą zalet geometrii drukarki cylindrycznej.
Przestrzen cylindryczna cechuje się zmienno ´ | sci ą rozdzielczo ´ | sci k ątowej w funkcji pro- ´
mienia, przez co zastosowanie redukcji mechanicznej lub mikrokrokowania silników krokowych
staje się konieczne aby zachowac odpowiedni ą rozdzielczo ´ | sć. Dotychczas zrealizowane imple- ´
mentacje opieraj ą się wył ącznie na systemach z mikrokrokowaniem silników krokowych, co moze˙
prowadzic do spadku momentu trzymaj ącego silników krokowych, a w konsekwencji powodowa ´ | c´
gubienie kroków b ądź powstanie artefaktów pionowych VFA (ang. vertical fine artifacts). Zasto-
sowanie dedykowanej redukcji mechanicznej w układzie napędowym bębna moze poprawi ˙ | c roz- ´
dzielczosć pozycjonowania bez nadmiernej pracy mikrokrokowej. ´

### 3. PODSTAWY MATEMATYCZNE

W rozdziale zajęto się zagadnieniami zwi ązanymi z transformacjami układów współrzędnych wykorzystywanymi w algorytmach generacji scie ´ zek narzędzia, oraz obliczeniami wymaganych roz- ˙ dzielczosci, na podstawie których oparto wymagania konstrukcji mechanicznej projektu. ´

### 3.1. Wytwarzanie w walcowym układzie współrzędnych

Pełne wykorzystanie potencjału geometrii drukarki cylindrycznej, zarówno pod względem własci- ´
wosci mechanicznych wytworzonych komponentów, jak i wizualnej jako ´ | sci ich wykonania, wy- ´
maga bezposredniej integracji walcowego układu współrzędnych w proces projektowania. Nieza- ´

leznie od liczby stopni swobody czy konfiguracji kinematycznej maszyny wykorzystuj ącej techno- ˙ logię FDM, przedmioty obrabiane wytwarzane s ą w procesie sekwencyjnego nakładania kolejnych warstw materiału. Orientacja płaszczyzn warstw względem geometrii wytwarzanego elementu
posiada znacz ący wpływ na rozkład napręze˙ n mechanicznych, jako ´ | sci wyko ´ | nczenia powierzchni ´
oraz dokładnosci odwzorowania krzywizn. Powierzchnie cylindryczne staj ą się najbardziej natu- ´

ralnym i efektywnie odwzorowywanym typem geometrii, podczas gdy powierzchnie płaskie, takie
jak sciany prostopadło ´ | scianu czy sze ´ | scianu w geometrii cylindrycznej podlegaj ą powstawaniu ´
charakterystycznych artefaktów efektu schodkowego.
3.1.1. Sposoby opisu przestrzeni

Tradycyjne programy projektowania wspomaganego komputerowo (CAD, ang. computer aided
design) definiuj ą przestrzen robocz ą w układzie kartezja ´ | nskim, wykorzystuj ąc trzy wzajemnie pro- ´
stopadłe osie do parametryzacji modeli trójwymiarowych. Z punktu widzenia projektanta istotna jest geometria przedmiotu w przestrzeni rzeczywistej, układ współrzędnych cylindrycznych i kar-
tezjanskich opisuj ą tę sam ą przestrze ´ | n dwoma ró ´ | znymi sposobami, zatem wykorzystanie układu ˙
cylindrycznego czy kartezjanskiego do opisu obiektu nie ma znaczenia. Z kolei z punktu widzenia ´ produkcyjnego w technologii FDM, przestrzen trójwymiarowa konstruowana jest z dyskretnych ´ wycinków przestrzeni dwuwymiarowej. Realizacja przestrzeni trójwymiarowej w układzie karte-
zjanskim jest bezpo ´ | srednio podzbiorem przestrzeni euklidesowej z dyskretyzacj ą wzdłu ´ | z osi Z. ˙

Natomiast opisanie przestrzeni rzeczywistej za pomoc ą warstw układu walcowego wymaga zastosowania ci ągłych płaszczyzn walcowych reprezentuj ących nieeuklidesow ą przestrzen dwuwy- ´

miarow ą.

3.1.2. Transformacje układów współrzędnych

Poniewaz projektowanie elementów odbywa się zazwyczaj w programach CAD, wykorzystuj ących ˙
kartezjanski układ współrzędnych jako podstawow ą przestrze ´ | n robocz ą, proces AM wymaga za- ´
stosowania odpowiednich transformacji do układu współrzędnych cylindrycznych. Równania ana-
lityczne transformacji pozwalaj ą na przejscie między układami cylindrycznym a kartezja ´ | nskim, ´
jednak mog ą byc one równie ´ | z wykorzystane jako narzędzie przekształcaj ące geometrie samego ˙

obiektu.

Układ współrzędnych kartezjanskich ´

Kartezjanski układ współrzędnych definiowany jest przez trzy wzajemnie prostopadłe osie ´
(OX, OY, OZ). Połozenie dowolnego punktu ˙ | P w przestrzeni jest jednoznacznie okreslone przez ´
trójkę współrzędnych (x, y, z), gdzie:
- x ∈ R – współrzędna wzdłuz osi ˙ | OX, reprezentuj ąca przesunięcie w kierunku poziomym,
- y ∈ R – współrzędna wzdłuz osi ˙ | OY, reprezentuj ąca przesunięcie w kierunku prostopadłym
do osi OX w płaszczyźnie poziomej,
- z ∈ R – współrzędna wzdłuz osi ˙ | OZ, reprezentuj ąca przesunięcie w kierunku pionowym.
Wektor połozenia punktu ˙ | P w układzie kartezjanskim mo ´ | ze by ˙ | c wyra ´ | zony jako: ˙

r®cart = x e®x + y e®y + z e®z =

x

y

z

, | (3.1)

gdzie e®x, e®y, e®z oznaczaj ą wersory (wektory jednostkowe) odpowiednich osi.

Układ współrzędnych walcowych

Walcowy (cylindryczny) układ współrzędnych to alternatywny system parametryzacji przestrzeni trójwymiarowej, szczególnie uzyteczny przy opisie geometrii osiowosymetrycznych oraz ruchu ˙
obrotowego. W tym układzie połozenie punktu ˙ | P jest okreslane przez współrzędne ´ | (r, θ, ℎ), gdzie:
- r ∈ [0, +∞) – promien, oznaczaj ący odległo ´ | sć punktu od osi ´ | OZ (osi obrotu),
- θ ∈ [0, 2π) – k ąt azymutalny, okreslaj ący pozycję k ątow ą względem wybranej płaszczyzny ´
odniesienia, domyslnie płaszczyzny ´ | X Z,
- ℎ ∈ R – wysokosć wzdłu ´ | z osi cylindra, odpowiadaj ąca współrzędnej ˙ | z w układzie kartezjan-´

skim.

Układ walcowy jest naturalnym wyborem dla maszyn o kinematyce obrotowej, takich jak
AL, poniewaz bezpo ˙ | srednio odpowiada stopniom swobody układu mechanicznego: obrót wokół ´

osi, przesuw radialny oraz przesuw wzdłuzny. ˙

Równania transformacji

Transformacja między układem kartezjanskim a walcowym jest odwracalna i opisana przez na- ´
stępuj ące zalezno ˙ | sci analityczne. Przekształcenie z układu walcowego ´ | (r, θ, ℎ) do układu karte-
zjanskiego ´ | (x, y, z) dane jest wzorami:

x = r cos(θ)

y = r sin(θ)

z = ℎ

, | (3.2)
Geometryczna interpretacja równan (3.2) polega na rzutowaniu punktu okre ´ | slonego przez ´
promien´ r i k ąt θ na płaszczyznę XY z zachowaniem współrzędnej wysokosci ´ z = ℎ.

Transformacja odwrotna, z układu kartezjanskiego ´ | (x, y, z) do układu walcowego (r, θ, ℎ),

wyraza się jako: ˙

r =

√︁
x

2 + y

2

θ = arctan 2(y, x)

ℎ = z

, | (3.3)
gdzie funkcja arctan 2(y, x) zwraca k ąt w pełnym zakresie [0, 2π) lub (−π, π], w zalezno ˙ | sci od ´
implementacji, uwzględniaj ąc znaki obu argumentów w celu jednoznacznego okreslenia ´ | cwiartki. ´
Współrzędna wysokosci ´ | ℎ pozostaje niezmieniona w obu układach, zatem, os´ OZ w układzie
kartezjanskim pokrywa się z osi ą cylindra w układzie walcowym. ´
Przedstawione równania transformacji opisuj ą globalne przekształcenie współrzędnych,
jednakze dla pełnego zrozumienia wła ˙ | sciwo ´ | sci geometrycznych tej transformacji konieczna jest ´
równiez analiza jej lokalnych charakterystyk ró ˙ | zniczkowych, pozwalaj ących okre ˙ | sli ´ c propagację ´
błędów pozycjonowania, zniekształcenia metryczne oraz zalezno ˙ | sć rozdzielczo ´ | sci przestrzennej. ´

Macierz Jakobianu transformacji

Macierz Jakobianu transformacji otrzymuje się przez obliczenie pochodnych cz ąstkowych współrzędnych kartezjanskich ´ (x, y, z) względem współrzędnych walcowych (r, θ, ℎ). Rózniczkuj ąc rów- ˙ nania (3.2), otrzymujemy macierz Jakobianu transformacji z układu walcowego do kartezjan-´

skiego:

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
cos(θ) −r sin(θ) 0
sin(θ) | r cos(θ) | 0
0 | 0 | 1
. | (3.4)

Wyznacznik macierzy Jakobianu wyraza się jako: ˙

|J| = r. | (3.5)
Dodatnia wartosć wyznacznika ´ | |J| = r, r > 0 potwierdza, ze transformacja zachowuje ˙
orientację przestrzenn ą, oraz okresla lokalny współczynnik skalowania objęto ´ | | | sci podczas trans- ´
formacji: element objętosci ´ | dVcart = dx dy dz w układzie kartezjanskim odpowiada elementowi ´

dVcyl = r dr dθ dℎ w układzie walcowym.
Widoczna jest liniowa zalezno ˙ | sć wyznacznika Jakobianu od promienia ´ | r, zatem dla sta-
łego przyrostu k ąta Δθ długosć łuku, któr ą przebywa punkt na powierzchni cylindra, zwiększa się ´

proporcjonalnie do promienia:

Δs = r · Δθ. | (3.6)
Celem utrzymania stałej rozdzielczosci liniowej druku na ró ´ | znych promieniach konieczne ˙
jest zastosowanie zmiennej rozdzielczosci k ątowej, lub odpowiednio wysokiej rozdzielczo ´ | | | | sci k ąto- ´
wej aby unikn ąc błędów dyskretyzacji w całej objęto ´ | sci roboczej. Ta wła ´ | sciwo ´ | sć ma bezpo ´ | srednie ´
konsekwencje zarówno dla mechanicznej konstrukcji tokarko-drukarki przyrostowej jak i programowej realizacji pozycjonowania.
3.1.3. Planowanie scie ´ zek walcowych w AM ˙

Transformacja trójwymiarowych modeli obiektów na instrukcje ruchu dla głowicy drukuj ącej, odbywa się zwykle za pomoc ą wyspecjalizowanego oprogramowania nazywanego slicerem. W tra-
dycyjnym podejsciu do wytwarzania przyrostowego, stosowanym w drukarkach kartezja ´ | | | | nskich, ´

metoda generowania scie ´ zek narzędzia polega na przecięciu siatki modelu 3D szeregiem płasz- ˙ czyzn równoległych do platformy roboczej. Kolejne warstwy s ą od siebie oddalone o odległosć´
wysokosci warstwy ´ | ℎl
lub Δz. Dla najczęsciej stosowanej dyszy o ´ | srednicy otworu wylotowego ´
równej 0,4 mm, typowa wysokosć warstwy mie ´ | sci się w przedziale od ´ | 0,12 mm do 0,32 mm. Na
podstawie tak utworzonych przekrojów płaskich algorytmy slicera obliczaj ą scie ´ | zki narzędzia oraz ˙
prędkosć podawania materiału. ´
Róznica płaszczyzn cięcia między układem kartezja ˙ | nskim a walcowym powoduje, ´ | ze˙
scie ´ | zki wygenerowane dla drukarki kartezja ˙ | nskiej nie mog ą zosta ´ | c bezpo ´ | srednio u ´ | zyte dla tokarko- ˙

drukarki przyrostowej. Analogiczne rozwi ązanie wymagałoby napisania programu sliceingu od podstaw. Bior ąc pod uwagę komplikacje współczesnych slicerów, napisanie nowego slicera jest zadaniem zbyt złozonym dla pojedynczego zespołu badawczego. W rozdziale pi ątym opisano ˙ alternatywne sposoby generowania scie ´ zek narzędzia opisane w literaturze, wraz z propozycj ą ˙

nowego rozwi ązania i kierunku rozwoju technologii.

W procesie cylindrycznego slicingu współsrodkowe powierzchnie walcowe, słu ´ | z ące do ˙
cięcia modelu 3D, definiowane s ą równaniem:

(x − xc)

2 + (y − yc)

2 = r

2
i
, | (3.7)

gdzie i ≥ 1 oznacza numer powierzchni cięcia a promienie kolejnych powierzchni walcowych
spełniaj ą warunek rmax | ≥ ri ≥ rmin. Minimalna wartosć promienia ´ | rmin | odpowiada wewnętrznej
powierzchni wytwarzanego elementu, natomiast rmax okresla jego zewnętrzn ą powierzchnię. Wy- ´
sokosć warstwy w druku cylindrycznym definiowana jest jako ró ´ | znica promieni dwóch s ąsiednich ˙

powierzchni cięcia:

ℎl = ri+1 − ri | dla i ≥ 1. | (3.8)

### 3.2. Wyzwania techniczne druku cylindrycznego

Rozdzielczosć k ątowa realizowanej trajektorii zmienia się w funkcji promienia 3.6. Zachowanie ´
odpowiedniej jakosci wydruku przy rosn ącej ´ | srednicy wytwarzanego elementu wymaga zastoso- ´
wania wystarczaj ącej rozdzielczosci k ątowej. Wyznaczenie odpowiedniej rozdzielczo ´ | sci zostało ´

przeprowadzone na podstawie analizy wpływu redukcji mechanicznej i mikrokrokowania na minimaln ą długosć kroku oraz akumulację błędów. ´

3.2.1. Analiza rozdzielczosci i dokładno ´ | sci pozycji ´
Rozdzielczosć liniowa w układzie kartezja ´ | nskim dla osi ´ | OX i OY, napędzanych za pomoc ą pasów

zębatych, wyraza się wzorem: ˙

Δx = Δy =

pb

ns · m

, | (3.9)
gdzie pb oznacza podziałkę paska zębatego (odległosć między zębami), ´ | ns | jest liczb ą kroków
silnika na obrót (standardowo 200 dla silników NEMA 17), a m reprezentuje liczbę mikrokroków. Analogicznie, dla osi OZ napędzanej srub ą trapezow ą: ´

Δz =

ps

ns · m

, | (3.10)

gdzie ps oznacza skok sruby trapezowej. ´

Dla typowej konfiguracji mechanicznej, rozdzielczosć liniowa poszczególnych osi karte- ´
zjanskich wyra ´ | za się następuj ąco: o ˙ | s´ OY napędzana za pomoc ą paska zębatego GT2 (podziałka

pb = 2 mm) z kołem zębatym 16-zębowym uzyskuje rozdzielczosć:´

Δy =

pb · Nt

ns · m

=

2 × 16
200 × 16
| = 0,01 mm, | | (3.11)
gdzie Nt | = 16 oznacza liczbę zębów na kole napędowym. Dla osi OZ wykorzystuj ącej srubę ´
trapezow ą T8 o skoku ps = 8 mm, rozdzielczosć wynosi: ´
| Δz = ps ns · m =
| 8 200 × 16
| = 0,0025 mm. | | (3.12)
Rozdzielczosć osi ´ | OZ (0,0025 mm) jest czterokrotnie wyzsza ni ˙ | z osi ˙ | OY (0,01 mm), dla
systemu składaj ącego się z najbardziej powszechnej kombinacji komponentów. Rozbiezno ˙ | sć mo ´ | zna ˙
wytłumaczyc na podstawie wymaga ´ | n dokładno ´ | sciowych dla poszczególnych kierunków. Wyso- ´
kosć warstwy w procesie FDM mie ´ | sci się zwykle w zakresie ´ | 0,08–0,3 mm, podczas gdy do-
kładnosć pozycjonowania w płaszczyźnie poziomej musi zapewnia ´ | c precyzyjne odwzorowanie ´
geometrii konturu przy szerokosci linii wynosz ącej około ´ | 0,4 mm dla standardowej dyszy. Nor-
malizuj ąc rozdzielczosć względem wymaganych wymiarów, otrzymujemy: dla osi ´ | | | OZ stosunek

Δz/ℎl ≈ 0,0025/0,08 ≈ 3,1%, natomiast dla osi OY stosunek Δy/(wl/2) ≈ 0,01/0,2 = 5% (gdzie wl ≈ 0,4 mm oznacza szerokosć linii). ´
W układzie walcowym rozdzielczosć k ątowa osi obrotowej przy zastosowaniu przekładni ´

mechanicznej wyraza się jako: ˙
| Δθ = 2π ns · m · ig
| , | | (3.13)
gdzie ig oznacza przełozenie reduktora (dla ˙ | ig = 1 przekładnia jest nieobecna). Rozdzielczosć´
łukowa na promieniu r wynosi wówczas:

Δs(r) = r · Δθ = r ·

2π

ns · m · ig

= k · r, | (3.14)

gdzie współczynnik proporcjonalnosci ´ k =

2π

ns ·m·ig

jest stały dla danej konfiguracji sprzętowej.
Ł ączne przełozenie układu obrotowego okre ˙ | slone jest jako iloczyn mikrokrokowania i prze- ´
łozenia mechanicznego: ˙ | itotal = m · ig. W tabeli 3.1 przedstawiono wartosci rozdzielczo ´ | sci łukowej ´
Δs dla róznych ł ącznych przeło ˙ | ze˙ n oraz wybranych warto ´ | sci promienia ´ | r, przy załozeniu standar- ˙

dowego silnika NEMA 17 (ns = 200).

Tabela 3.1: Rozdzielczosć łukowa ´ | Δs [mm] w funkcji promienia r i ł ącznego przełozenia układu obrotowego ˙
dla silnika NEMA 17

r [mm]

Ł ączne przełozenie ˙ | itotal = m · ig
| 1 | 16 | 32 | 64
10 | 0,0196 | 0,00123 | 0,000614 | 0,000307
50 | 0,0982 | 0,00614 | 0,00307 | 0,00153
100 | 0,1963 | 0,0123 | 0,00614 | 0,00307
200 | 0,3927 | 0,0245 | 0,0123 | 0,00614
Z analizy tabeli 3.1 wynika, ze standardowy silnik krokowy NEMA17 (bez przeło ˙ | zenia ˙
itotal = 1) osi ąga minimaln ą rozdzielczosć łukow ą na promieniu ´ | r = 200 mm o wartosci a ´ | z˙ 0,4 mm.
Wartosć´ 0,4 mm 40 krotnie przewyzsza rozdzielczo ˙ | sć osi ´ | OX, co spowodowałoby duze niedokład- ˙
nosci pomiarowe i nierównomierno ´ | sć rozkładu materiału. Ł ączne przeło ´ | zenie ˙ | itotal = 16 redukuje
rozdzielczosć łukow ą szesnastokrotnie, co dla ´ | r = 200 mm daje wartosć´ 0,0245 mm, juz zbli ˙ | zon ą ˙

do typowej rozdzielczosci drukarek kartezja ´ | nskich, wci ą ´ | z jednak niewystarczaj ąc ą. Je ˙ | sli za me- ´
trykę docelowej rozdzielczosci przyjmiemy warto ´ | sć rozdzielczo ´ | sci na osi ´ | OX, wynosz ąc ą 0,01 mm
jako docelow ą wartosć, preferowana kombinacja wymaga ł ącznej redukcji ´ | ig ≈ 32.
Realizacja ł ącznego zadanego przełozenia jest mo ˙ | zliwa poprzez ró ˙ | zne kombinacje mikro- ˙
krokowania i redukcji mechanicznej. Przykładowo, ł ączne przełozenie ˙ | itotal = 16 mozna osi ągn ą ˙ | c´

stosuj ąc mikrokrokowanie 1/16 bez przekładni (m = 16, ig = 1), lub mikrokrokowanie 1/8 z przekładni ą 2:1 (m = 8, ig = 2). Wybór konkretnej kombinacji zalezy od kompromisu między momen- ˙ tem obrotowym silnika krokowego (maleje wraz ze wzrostem mikrokrokowania), płynnosci ą ruchu ´
(wzrasta przy wyzszym mikrokrokowaniu) oraz zło ˙ | zono ˙ | sci ą konstrukcji mechanicznej (ro ´ | snie wraz ´
ze wzrostem przełozenia ˙ | ig). Poniewaz moment bezwładno ˙ | sci bębna roboczego, w poł ączeniu z ´
oddziaływaniem masy tworzonego wydruku, moze osi ąga ˙ | c wysokie warto ´ | sci momentu siły dzia- ´
łaj ącej na silnik krokowy, przy duzej warto ˙ | sci mikrokrokowania istnieje ryzyko przekroczenia mo- ´
mentu trzymaj ącego silnika. Redukcja mechaniczna przynosi zarówno poprawę rozdzielczosci, ´ jak i przewagę mechaniczn ą redukuj ąc ą oddziaływanie momentu bezwładnosci bębna na silnik ´
krokowy, zatem zwiększenie wartosci redukcji mechanicznej umo ´ | zliwia zastosowanie większego ˙

stopnia mikrokrokowania.

Analiza propagacji błędów

Analiza propagacji błędów pozycjonowania między układami współrzędnych wymaga uwzględnie-
nia rózniczkowych zale ˙ | zno ˙ | sci transformacji. Niepewno ´ | sć pozycji w układzie kartezja ´ | nskim wyra ´ | za˙

się jako:

σpos,cart =

√︃

σ

2
| | | x + σ
| | | 2 y + σ

2

z

, | (3.15)
podczas gdy w układzie walcowym odpowiednie wyrazenie przyjmuje posta ˙ | c:´

σpos,cyl =

√︃

σ

2
r + (r · σθ )

2 + σ

2
ℎ
. | (3.16)

Składnik (r · σθ )

2 ujawnia zalezno ˙ | sć niepewno ´ | sci pozycji od promienia. Wpływ błędu k ątowego ´

σθ na całkowit ą niepewnosć pozycjonowania nie jest liniowy. ´
Propagacja błędów z układu walcowego do kartezjanskiego wynika bezpo ´ | srednio z ma- ´
cierzy Jakobianu transformacji (3.4). Rózniczkuj ąc równania transformacji (3.2) i stosuj ąc prawo ˙
propagacji niepewnosci, otrzymujemy składowe błędu w układzie kartezja ´ | nskim: ´

σ

2
x =
∂x

∂r 2

σ

2
r +
∂x

∂θ 2

σ

2

θ = cos²
(θ) σ

2
r + r

2

sin²
(θ) σ

2
θ
, | (3.17)

σ

2
y =
∂y

∂r 2

σ

2
r +
∂y

∂θ 2

σ

2

θ = sin²
(θ) σ

2
r + r

2

cos²
(θ) σ

2
θ
, | (3.18)

σ

2
z = σ

2
ℎ
. | | (3.19)
Sumuj ąc składowe (3.17) i (3.18), z uwzględnieniem tozsamo ˙ | sci trygonometrycznej ´ | sin²
(θ)+
cos²
(θ) = 1, otrzymujemy:

σ

2
x + σ

2
y = σ

2

r

(cos²

(θ) + sin²
(θ)) + r

2σ

2
θ

(sin²

(θ) + cos²
(θ)) = σ

2
r + r

2σ

2
θ
, | (3.20)
co potwierdza niezalezno ˙ | sć całkowitego błędu pozycji od k ąta ´ | θ oraz liniow ą zalezno ˙ | sć składowej ´

k ątowej od promienia r.
Przyjmuj ąc, ze błędy pozycjonowania s ą zdominowane przez rozdzielczo ˙ | | | | sć dyskretn ą ´
układu mechanicznego, mozna aproksymowa ˙ | c niepewno ´ | sci jako: ´ | σr | ≈ Δr, σθ ≈ Δθ, σℎ ≈ Δz.

Z równania (3.20) wynika, ze składowa k ątowa błędu pozycji wynosi ˙ | r · σθ = r · Δθ, zatem jest
analogiczna do rozdzielczosci łukowej ´ | Δs(r) z tabeli 3.1.
Względny wkład składowej k ątowej do całkowitego błędu pozycjonowania mozna okre ˙ | sli ´ c´

obliczaj ąc procentowy udział (r · σθ )

2 w całkowitym kwadracie błędu. Zakładaj ąc typowe wartosci ´

błędów dla osi radialnej i wysokosci porównywalne z osiami kartezja ´ | nskimi ( ´ | σr | ≈ 0,01 mm, σℎ ≈

0,0025 mm), w tabeli 3.2 przedstawiono całkowity bł ąd pozycjonowania oraz procentowy udział składowej k ątowej dla wybranych konfiguracji.

Tabela 3.2: Całkowity bł ąd pozycjonowania σpos,cyl i procentowy udział składowej k ątowej dla σr = 0,01 mm,

σℎ = 0,0025 mm

r [mm] | itotal | r · σθ [mm] | σpos,cyl [mm] | Udział k ątowy [%]
100 | 16 | 0,0123 | 0,0161 | 58,7
100 | 32 | 0,00614 | 0,0120 | 26,2
200 | 16 | 0,0245 | 0,0266 | 85,0
200 | 32 | 0,0123 | 0,0161 | 58,7
200 | 64 | 0,00614 | 0,0120 | 26,2

W tabeli 3.2 przedstawiono całkowite znaczenie błędu k ątowego w układzie walcowym.
Dla duzych promieni roboczych ( ˙ | r = 200 mm) przy niewystarczaj ącym przełozeniu ( ˙ | itotal = 16),
składowa k ątowa stanowi az˙ 85% całkowitego kwadratu błędu wpływaj ącego na precyzję pozy-
cjonowania. Zwiększenie przełozenia do ˙ | itotal = 32, wartosci uznanej jako docelow ą na podstawie ´
analizy tabeli 3.1, redukuje ten udział do 59% – co oznacza, ze udział błędu dominuje i przewy ˙ | z-˙
sza ł ączny bł ąd osi OX i OZ. Wartosć redukcji ´ | itotal = 64 obniza udział błędu do ˙ | 26%, czyni ąc błędy
wszystkich osi porównywalnymi. Zatem dla zachowania zrównowazonej precyzji przestrzennej na ˙
duzych promieniach roboczych ( ˙ | r ≥ 200 mm), wymagane jest ł ączne przełozenie ˙ | itotal ≥ 64.

Wnioski analizy rozdzielczosci ´

Mikrokrokowanie silników krokowych, zapewnia płynniejszy ruch, redukcję hałasu oraz lepsz ą
jakosć wyko ´ | nczenia powierzchni. Jednak ´ | ze metoda ta charakteryzuje się obni ˙ | zeniem momentu ˙
trzymuj ącego wraz ze wzrostem stopnia mikrokrokowania, co ogranicza mozliwo ˙ | sć wytwarzania ´
obiektów o duzej bezwładno ˙ | sci oraz wymusza redukcję prędko ´ | sci drukowania poprzez redukcję ´
przyspieszenia i warto ´ | sci natychmiastowej zmiany przy ´ | spieszenia ´ | jerk. Alternatywnym rozwi ąza-

niem jest zastosowanie redukcji mechanicznej w układzie obrotowym, co pozwala na utrzymanie pełnego momentu obrotowego przy jednoczesnym zwiększeniu rozdzielczosci k ątowej. Praktycz- ´ nym rozwi ązaniem jest poł ączenie obydwu metod i dostosowania wymaganej rozdzielczosci do ´
załoze˙ n wymiarowych maszyny. Na podstawie oblicze ´ | n wpływu błędów składowych zdecydowano ´
się na docelow ą, ł ączn ą wartosć przeło ´ | zenia ˙ | itotal ≥ 64.

### 4. PROJEKT I ARCHITEKTURA SYSTEMU

Nadrzędnym celem przyjętej strategii konstrukcyjnej była maksymalizacja dostępnosci oraz mo ´ | z-˙
liwosć odwzorowania projektu. Starano się wykorzysta ´ | c rozwi ązania ´ | open source, rozpowszech-

nione w drukarkach typu RepRap oraz ich komercyjnych odpowiednikach. Zastosowane komponenty, zarówno mechaniczne jak i elektroniczne, s ą powszechnie stosowane w konstrukcjach drukarek 3D i maszyn CNC, co zapewnia wysok ą dostępnosć i upraszcza proces adaptacji istnie- ´ j ących rozwi ązan. Całkowity koszt materiałów mechanicznych oraz elektronicznych wyniósł około ´

800 PLN.

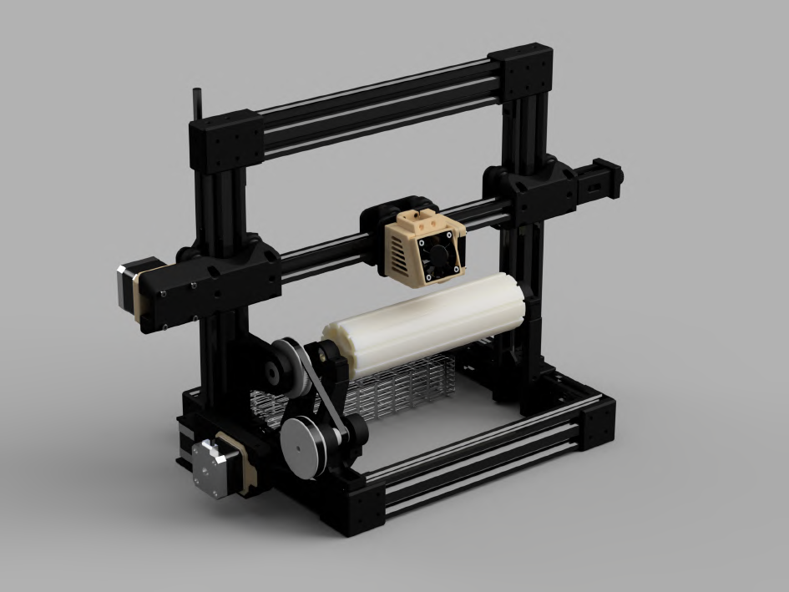
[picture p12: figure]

Rysunek 4.1: Render stworzonego projektu CAD drukarki

### 4.1. Projekt mechaniczny

Projekt konstrukcji mechanicznej AL został wykonany z uwzględnieniem załoze˙ n kompatybilno ´ | sci ´
rozwi ązan´ open source oraz ograniczen bud ´ | zetowych. Głównym elementem konstrukcyjnym s ą ˙
profile aluminiowe. Pozostałe częsci, w tym: elementy ł ącz ące, wsporniki i przekładnie wykonano ´

metod ą druku 3D. W implementacji skorzystano z gotowego hotendu typu MK8, oraz nakładki ekstrudera Bowden na silnik krokowy. Wizualizację projektu CAD drukarki, stworzonego na potrzeby projektu, przedstawiono na ilustracji 4.1.

4.1.1. Rama konstrukcyjna

W konstrukcji wykorzystano profile aluminiowe o przekrojach 20 × 20 mm oraz 20 × 40 mm, które
umozliwiaj ą zbudowanie sztywnej konstrukcji, oraz pełni ą funkcję prowadnic dla ło ˙ | zysk rolkowych. ˙
Ramę podstawy oraz bramę pionow ą wykonano z profili o przekroju 20 × 40 mm, system prze-
suwny, przenosz ący głowicę drukuj ąc ą, skonstruowano z lzejszego profilu 20 ˙ | × 20 mm. W kana-
łach profilu aluminiowego poprowadzono pasek napędowy GT2, realizuj ący ruch liniowy głowicy drukuj ącej, napędzany przez silnik krokowy.

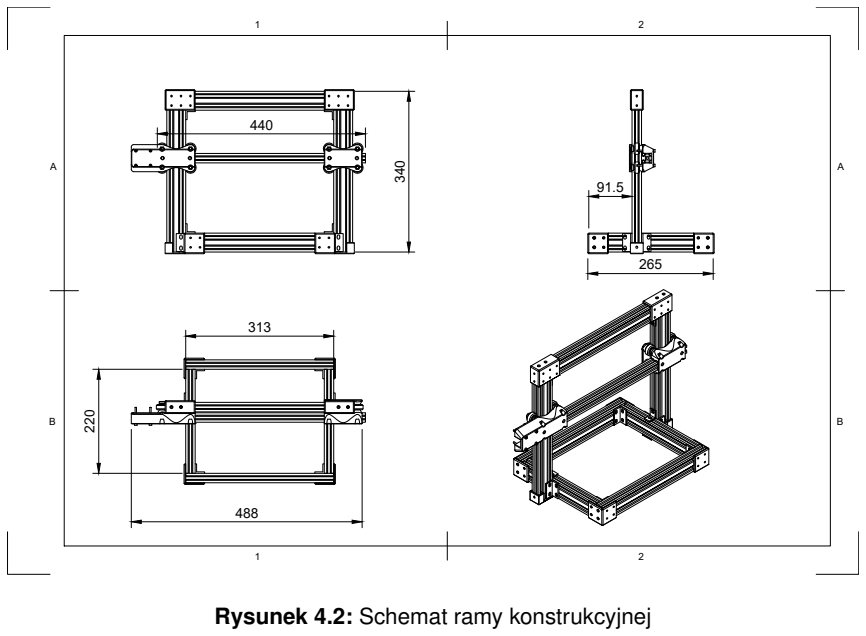
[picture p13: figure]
265 ³⁴⁰; Rysunek 4.2: Schemat ramy konstrukcyjnej

Na rysunku 4.2 przedstawiono schemat ramy konstrukcyjnej, wymiary podano w milimetrach. Segment A1 zawiera rzut frontalny; segment B1 - rzut z góry; segment A1 - rzut boku; segment B2 - rzut izometryczny.

Ł ączniki profili aluminiowych zaprojektowano na podstawie profilu przekroju poprzecz-
nego profilu aluminiowego. Ł ączniki posiadaj ą szyny umozliwiaj ące wsunięcie ich na ko ˙ | nce profi- ´
lów, a poł ączenia zrealizowano z uzyciem nakrętek typu T. ˙
4.1.2. Dobór materiałów do druku 3D komponentów konstrukcyjnych

Wybór odpowiednich polimerów drukowanych elementów uwzględniał wymagania mechaniczne
i termiczne. Częsci bezpo ´ | srednio s ąsiaduj ące z elementami generuj ącymi znacz ące ilo ´ | sci ciepła, ´
tj. silnikami krokowymi oraz ekstruderem, wykonano z PC/ABS, stopu polimerowego poliwęglanu (PC, ang. polycarbonate) i akrylonitrylo-butadieno-styrenu (ABS, ang. acrylonitrile butadiene styrene). Materiał PC charakteryzuje się wysok ą temperatur ą uplastycznienia (temperatura zeszklenia Tg ≈ 147°C) oraz wyj ątkowo wysokim punktem topnienia (Tm ≈ 267°C), co oznacza ze jest on ˙ odporny na odkształcenia termiczne w s ąsiedztwie grzałki ekstrudera, oraz przy bezposrednim ´ kontakcie z silnikami krokowymi. Silniki krokowe w warunkach długotrwałej pracy mog ą osi ągac´ temperatury obudowy w zakresie od 60°C do 80°C. Jako dodadkowy mechanizm odprowadzania ciepła, wykorzystano metalowe elementy ramy, które pełni ą w tym przypadku funkcję radiatora, rozpraszaj ąc ciepło generowane przez uzwojenia silników na duz ą powierzchnię. ˙

Czysty PC wykazuje bardzo wysoki skurcz liniowy rzędu 1,0 do 2,5%, co wi ąze się z eks- ˙ tremalnie wysokim ryzykiem deformacji i odklejania się od stołu roboczego podczas procesu druku. Z tego względu wytwarzanie komponentów z czystego PC wymaga stosowania zamkniętej
komory druku z kontrolowan ą temperatur ą otoczenia. Poniewaz większo ˙ | sć maszyn konsumenc- ´
kich nie posiada kontroli temperatury otoczenia druku, zastosowano filament z domieszk ą ABS. Dodanie domieszki ABS (którego skurcz liniowy wynosi 0,8 do 1,5%) do kompozytu PC/ABS zna-
cz ąco obniza całkowity skurcz mieszanki oraz poprawia adhezję do powierzchni roboczej, umo ˙ | z-˙

liwiaj ąc produkcję częsci na drukarkach nieposiadaj ących komory grzewczej. Wynikowy filament ´ nadal posiada wysoki skurcz, więc w celu dalszej minimalizacji odkształcen termicznych, ele- ´

menty zaprojektowano z mozliwie płask ą geometri ą podstawy oraz z maksymaln ą powierzchni ą ˙ kontaktu ze stołem roboczym. Proces druku realizowano z zastosowaniem podwyzszonej tempe- ˙
ratury stołu roboczego (Tb > 100°C, zalecane 110 do 120°C) a takze funkcji ˙ | brim o szerokosci 15 ´
do 20 mm, która zwiększa powierzchnię przyczepnosci warstwy dolnej i przeciwdziała odkształ- ´
ceniom narozników, oraz funkcji ˙ | draft-shield zmniejszaj ącej ryzyko powstania pr ądów konwekcyj-
nych chłodz ących produkowany element. Taka konfiguracja procesu druku umozliwia niezawodne ˙ wytwarzanie elementów PC/ABS na powszechnie dostępnych drukarkach konsumenckich, takich jak Ender 3 lub Prusa i3.

Pozostałe komponenty konstrukcyjne, charakteryzuj ące się umiarkowanymi wymaganiami mechanicznymi oraz niepodlegaj ące długotrwałemu oddziaływaniu podwyzszonych temperatur, ˙ wykonano z polilaktydu (PLA, ang. polylactic acid). Materiał PLA wyróznia się wyj ątkow ą łatwo- ˙ sci ą przetwarzania w technologii FDM, wykazuje minimalny skurcz liniowy (rzędu 0,3 do 0,5%), ´ drukuje w niskich temperaturach ekstruzji (190 do 220°C) i nie wymaga podgrzewania stołu roboczego. Ograniczeniem materiału PLA jest niska temperatura zeszklenia (Tg ≈ 60°C), powyzej ˙
której traci sztywnosć, oraz do ´ | swiadcza drastycznego pogorszenia wła ´ | sciwo ´ | sci mechanicznych ´
(traci nosno ´ | sć), co dyskwalifikuje jego wykorzystanie w elementach bezpo ´ | srednio s ąsiaduj ących ´
z źródłami ciepła.

### 4.2. Kinematyka

Układ kinematyczny AL bazuje na budowie tradycyjnego układu kartezjanskiego stosowanego ´ w drukarkach FDM, oraz kinematyki cylindrycznej, w której jedna z osi liniowych zostaje zast ąpiona osi ą obrotow ą. Transformacja osi OY, realizuj ącej standardowo przesuw liniowy w kierunku
poprzecznym, na os obrotow ą umo ´ | zliwia ci ągły obrót cylindrycznego bębna roboczego wokół osi ˙
OX. Pozostałe dwie osie zachowuj ą ruch liniowy, zapewniaj ąc pełn ą swobodę pozycjonowania dyszy w przestrzeni roboczej urz ądzenia.
Realizację ruchów liniowych osi OX i OZ oparto na sprawdzonych rozwi ązaniach powszechnie stosowanych w konstrukcjach drukarek typu RepRap. Os OZ wykorzystuje układ bramy, ´ po której w kierunku pionowym przemieszcza się belka wspieraj ąca głowicę drukuj ąc ą. Profile aluminiowe bramy pełni ą rolę prowadnic liniowych, a napęd realizowany jest za pomoc ą sruby ´

trapezowej TR8×8 poł ączonej z silnikiem krokowym za pomoc ą sprzęgła elastycznego.
Os X napędzana jest za pomoc ą paska zębatego GT2, napiętego między napędowym ´

kołem zębatym zamontowanym na wale silnika krokowego, a kołem biernym z zespołem napinacza. Karetka głowicy porusza się wzdłuz belki i podobnie jak w przypadku osi bramy wykorzystuje ˙ rolki z łozyskami 608ZZ. ˙

4.2.1. Napęd osi obrotowej
Projekt układu napędowego osi obrotowej OY wymaga umozliwienia monta ˙ | zu wymiennych bęb- ˙
nów roboczych o róznych ˙ | srednicach, oraz redukcję mechaniczn ą ´ | itotal ≥ 64, niezbędn ą do osi ą-
gnięcia wystarczaj ącej rozdzielczosci k ątowej pozycjonowania. W zespole napędu istotna jest mi- ´
nimalizacja luzu mechanicznego. Obecnosć luzu prowadzi do utraty dokładno ´ | sci pozycjonowania ´
oraz powstawania artefaktów powierzchniowych przy częstych zmianach kierunku obrotu bębna.
W celu zachowania maksymalnego momentu trzymaj ącego d ązono do minimalizacji zale ˙ | zno ˙ | sci ´

systemu od mikrokrokowania silnika krokowego.

Podczas projektowania konstrukcji starano się osi ągn ąc rozwi ązanie o jak największej re- ´

dukcji mechanicznej, ostatecznie zrealizowano ł ączn ą redukcję mechaniczn ą na poziomie 16:1, która w poł ączeniu z 8-krotnym mikrokrokowaniem sterowników TMC2208 zapewnia wymagan ą
rozdzielczosć. Podczas testów momentów trzymaj ących stwierdzono, ´ | ze stopie ˙ | n redukcji mecha- ´
nicznej odpowiednio zmniejsza obci ązenie silnika, był on w stanie realizowa ˙ | c stabiln ą pracę rów- ´
niez w trybie 16-krotnego mikrokrokowania, które zapewniło cichsz ą pracę układu. Finalna kon- ˙ strukcja posiada 256-krotn ą redukcję itotal, czyli rozdzielczosć wynosz ąc ą 51 200 kroków na pełny ´ obrót bębna.

Analiza porównawcza mechanizmów redukcji

W celu spełnienia wymagan układu napędowego bębna roboczego, w pocz ątkowej fazie projektu ´
zidentyfikowano koniecznosć minimalizacji liczby przej ´ | sć mechanicznych w ła ´ | ncuchu kinematycz- ´

nym. Kazde poł ączenie między zębatkami lub innymi ruchomymi elementami wprowadza dodat- ˙ kowy luz mechaniczny kumuluj ący się w całym układzie. Teoretycznie mozliwe było osi ągnięcie ˙
wymaganej rozdzielczosci k ątowej poprzez ró ´ | zne kombinacje redukcji mechanicznej i stopnia mi- ˙

krokrokowania silnika, jednak priorytetem była redukcja mechaniczna.

Osi ągnięcie wysokich przełoze˙ n mechanicznych w przekładniach jednoparowych wymaga ´ znacznej róznicy ˙ srednic kół zębatych (stosunek liczby zębów koła napędzanego do napędzaj ą- ´

cego), a ze względu na ograniczon ą precyzję wymiarow ą drukarek FDM, umozliwiaj ących nie- ˙ zawodne wytwarzanie zębatek o module nie większym niz około 0,75 mm, konieczne byłoby ˙ znacz ące zwiększenie promienia kół zębatych w celu uzyskania wystarczaj ącej liczby zębów, co prowadziłoby do powstania rozwi ązania o znacznych gabarytach, uniemozliwiaj ących uzyskanie ˙ kompaktowej konstrukcji. Podczas planowania konstrukcji mechaniczenj testowano rozwi ązania o znacznej redukcji mechanicznej, jednak jak pokazały otrzymane wyniki fizycznej implementacji, znaczna redukcja nie jest konieczna, a rozwi ązanie posiadaj ące 8-krotn ą redukcję mechaniczn ą w poł ączeniu z 8-krotn ą prac ą mikrokrokow ą spełnia wymagania rozdzielczosci. ´

Przekładnia planetarna

Pierwszym obiecuj ącym kandydatem rozpatrywanym jako potencjalny mechanizm redukcji była przekładnia planetarna. Przekładnie planetarne składaj ą się z centralnego koła zębatego słonecznego, zestawu satelitów oraz zewnętrznego koła zębatego wiencowego. Wszystkie komponenty ´

przekładni planetarnej s ą teoretycznie mozliwe do wytworzenia w technologii druku 3D, a mecha- ˙ nizm ten oferuje wysokie przełozenia w kompaktowej formie konstrukcyjnej. Przekładne plane- ˙ tarne wykorzystuj ą wiele punktów styku między zębatkami co pozwala na przeniesienie większych
obci ąze˙ n w stosunku do tradycyjnych zębatek prostych. Istnienie wielu stopni przeło ´ | zenia wpro- ˙
wadza potencjał znacznego luzu mechanicznego wynikaj ącego z kumulacji luzów w poszczegól-
nych zazębieniach, który moze wywoływa ˙ | c problemy, bior ąc pod uwagę niedokładno ´ | sci druku. ´

Wstępne testy eksperymentalne przeprowadzone w fazie planowania projektu z wykorzystaniem
publicznie dostępnego modelu przekładni planetarnej o przełozeniu 37:1 [18] wykazały, ˙ | ze układ ˙
ten charakteryzuje się zbyt duzymi luzami k ątowymi przekraczaj ącymi akceptowalne warto ˙ | sci dla ´

zastosowania w precyzyjnym pozycjonowaniu osi obrotowej drukarki.

Przekładnia slimakowa ´

Kolejnym analizowanym rozwi ązaniem była przekładnia slimakowa, charakteryzuj ąca się zdolno- ´
sci ą do osi ągania wysokich warto ´ | sci przeło ´ | zenia. Zaprojektowano i przetestowano przekładnię ˙
slimakow ą o przeło ´ | zeniu 42:1, z parametrami: moduł ˙ | m = 1,25 mm, k ąt przyporu PA = 14,5°,
liczba zębów z = 42, k ąt helisy linii srubowej ´ | H A = 2,2°.

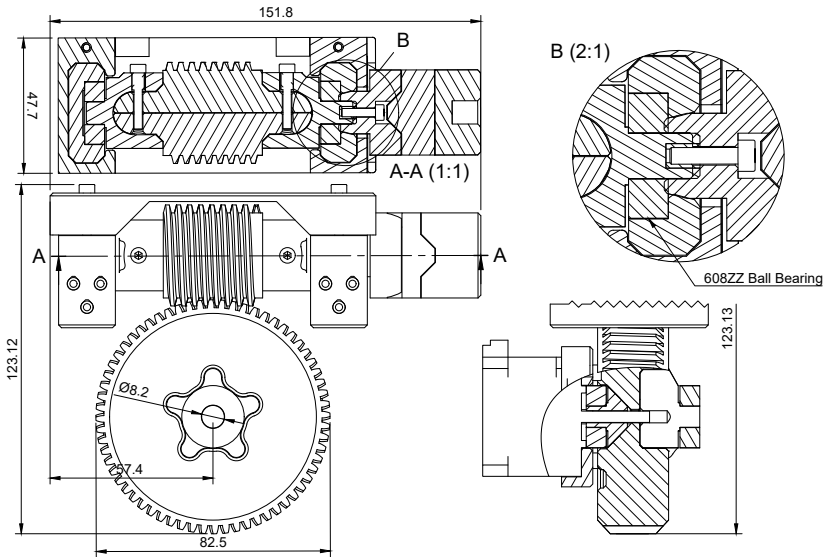
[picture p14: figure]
608ZZ Ball Bearing

Rysunek 4.3: Schemat wykonanej przekładni slimakowej z kompensacj ą luzu ´

W celu eliminacji luzu mechanicznego zaprojektowano mechanizm kompensacji luzu poprzez docisk spręzynowy, oparty koncepcyjnie na publicznie dostępnym projekcie [19]. Mecha- ˙
nizm opiera się na montazu zębatki ˙ | slimakowej w ruchomej szynie, dociskanej zestawem sprę ´ | zyn ˙

do koła zębatego. Implementacja opisanego rozwi ązania nie przyniosła oczekiwanych rezulta-
tów i ostatecznie została uznana za nieudan ą w kontekscie wymaga ´ | n projektu. Docisk sprę ´ | zy- ˙
nowy spowodował powstanie nadmiernych oporów ruchu w przekładni. Dodatkowo zastosowanie sprzęgła Oldhama, wytworzonego w technologii FDM, ponownie wprowadziło luz mechaniczny do układu kinematycznego, niweluj ąc korzysci wynikaj ące z eliminacji luzu w samym zazębieniu ´ slimakowym. ´

Przekładnia paskowa dwustopniowa

Ostatecznym rozwi ązaniem zastosowanym w prototypie AL jest dwustopniowa przekładnia paskowa wykorzystuj ąca pasy zębate GT2 oraz koła zębate o liczbach zębów 20 oraz 80. Układ składa się z dwóch sekwencyjnie poł ączonych stopni redukcji, z których kazdy realizuje prze- ˙
łozenie 1:4, daj ące ł ączne przeło ˙ | zenie mechaniczne 1:16. Zastosowanie ło ˙ | zysk kulkowych typu ˙
608ZZ do podparcia wszystkich wałów posrednich oraz wału napędzaj ącego bęben zapewnia ´
płynny ruch obrotowy charakteryzuj ący się niskimi oporami tarcia. Niskie obci ązenie silnika umo ˙ | z-˙
liwiło zastosowanie 16-krotnego mikrokrokowania, oraz trybu pracy StealthChop sterowników TMC2208, realizuj ącym aktywne wirtualne wygładzanie krzywej pr ądowej. Schemat przekładni przedstawiono na rysunku 4.4.
Regulacja napięcia pasów napędowych polega na przesunięciu wału przekładni wzdłuz˙
profilu aluminiowego. Połozenie silnika krokowego napędzaj ącego pierwszy stopie ˙ | n przekładni ´

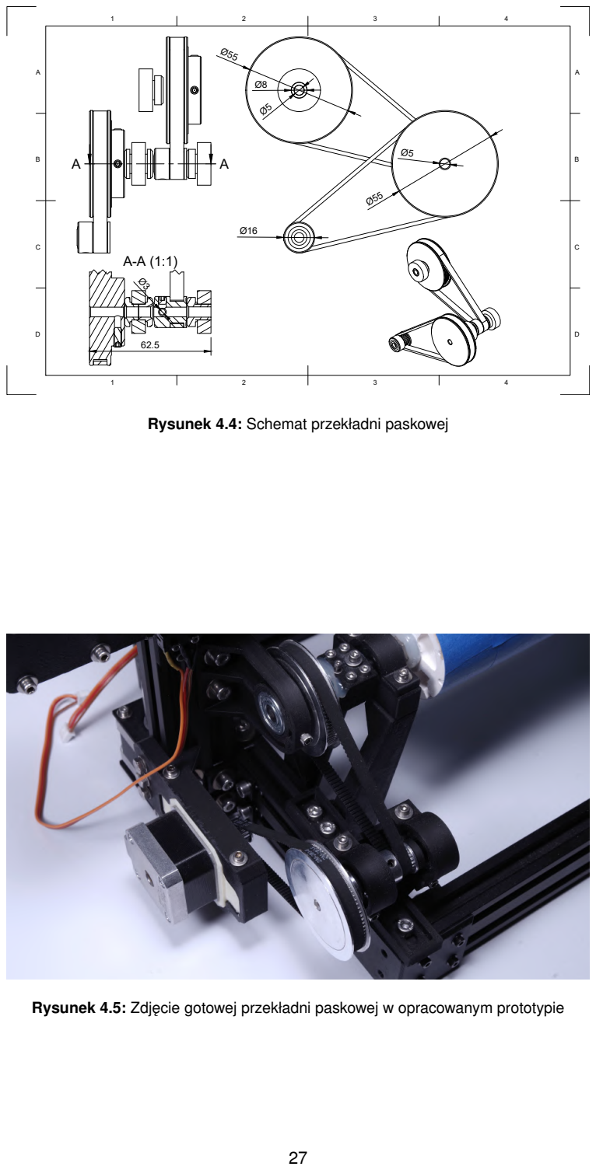
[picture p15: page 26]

Rysunek 4.4: Schemat przekładni paskowej

Rysunek 4.5: Zdjęcie gotowej przekładni paskowej w opracowanym prototypie

oraz połozenie napędu bębna roboczego mo ˙ | zna regulowa ˙ | c indywidualnie, co umo ´ | zliwia kontrolę ˙
stopnia napięcia indywidualnych odcinków pasów.
4.2.2. Projekt głowicy drukuj ącej
W klasycznych drukarkach kartezjanskich poło ´ | zenie dyszy w płaszczyźnie roboczej jest jedno- ˙
znacznie okreslone przez układ współrzędnych, w konfiguracji AL dysza musi znajdowa ´ | c się ´
w jednej płaszczyźnie z osi ą obrotu bębna roboczego. W przeciwnym razie koncentrycznosć tra- ´ jektorii druku nie zostanie zachowana, a odległosć dyszy od powierzchni roboczej będzie zmienna ´
podczas obrotu bębna. Niezbędne jest zatem wyposazenie głowicy w mechanizm umo ˙ | zliwiaj ący ˙
regulację pozycji dyszy w kierunku osi OY. Projekt głowicy przedstawiono na rysunku 4.6.

1

A

2 | 3 | 4 | 5 | 6 | 7 | 8
1 | 2 | 3 | 4 | 5 | 6 | 7 | 8

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
Dysza MK6

Blok grzewczy

Radiator przerwy
grzewczej

1:2 ⁷⁰.61

57.44

58.35

Rysunek 4.6: Schemat głowicy drukuj ącej

Głowicę wyposazono w wentylator chłodz ący przerwę grzewcz ą ˙ | hotendu oraz w wentyla-
tor chłodzenia częsci (ang. ´ | part cooling fan). Zadaniem radiatora przerwy grzewczej jest zapobie-
ganie propagacji ciepła w górę kanału podawania filamentu. Niekontrolowane nagrzewanie górnej częsci kanału prowadzi do przedwczesnego uplastycznienia filamentu poza komor ą topnienia, co ´
moze skutkowa ˙ | c zatkaniem kanału podawania. Wentylator chłodzenia czę ´ | sci zapewnia chłodze- ´

nie ekstrudowanego materiału tuz po jego depozycji na powierzchni roboczej. Kanał powietrzny ˙
kieruje strumien powietrza bezpo ´ | srednio na obszar tu ´ | z poni ˙ | zej dyszy, gdzie następuje krzepnięcie ˙

wyekstrudowanego materiału.

### 4.3. Elektronika i system sterowania

Funkcje centralnej jednostki steruj ącej pełni płyta BTT SKR V1.4 Turbo, posiadaj ąc ą 32-bitowy mikrokontroler ARM Cortex-M3 (LPC1769, taktowanie 120 MHz) oraz natywne wsparcie oprogramowania Mariln. Architektura 32-bitowa i szybkie taktowanie procesora umozliwia dokładniejsz ą ˙ interpolację współrzędnych cylindrycznych, przy wysokich prędkosciach druku lub wysokiej gę- ´ stosci punktów. ´

Sterowanie silnikami krokowymi NEMA 17 realizuj ą sterowniki TMC2208, komunikuj ące się z płyt ą główn ą poprzez interfejs UART (ang. Universal Asynchronous Receiver-Transmitter). Układ grzewczy głowicy drukuj ącej składa się z grzałki kapsułowej o mocy 40 W. Pomiar temperatury realizuje termopara rezystancyjna NTC 100k (ang. Negative Temperature Coefficient).
Wykrywanie pozycji krancowych osi ´ | OX i OZ realizuj ą mechaniczne przeł ączniki krancowe, mon- ´

towane w punktach odpowiadaj ących pozycji bazowej kazdej z osi, wykorzystywanej podczas ˙ procedury bazowania (ang. homing), wywoływanej podczas inicjalizacji drukarki.

4.3.1. Konfiguracja poł ączen elektrycznych ´

W prototypie drukarki wykorzystano cztery sterowniki TMC2208 zainstalowane w gniazdach X,
Y, ZA oraz E0. W konfiguracji domyslnej sterowniki pracuj ą w trybie ´ | legacy, w którym poziom
mikrokrokowania jest ustalany sprzętowo za pomoc ą pinów MS1, MS2 oraz MS3. Aby aktywo-
wac komunikację UART umo ´ | zliwiaj ąc ą programow ą kontrolę parametrów pracy sterowników, na- ˙
lezy usun ą ˙ | c fabryczne zworki zwieraj ące piny MS1, MS2 oraz RST/SLP, a następnie umie ´ | sci ´ c´
zworkę na pinie MS3, ustawiaj ąc go w stan wysoki (logiczna 1). Konfiguracja UART w sterownikach TMC2208, umozliwia dwukierunkow ą wymianę danych z układami, w tym ustawienie pr ądu ˙ referencyjnego, trybu pracy, oraz odczyt diagnostyczny stanu sterowników.

Poł ączenia elektryczne pomiędzy płyt ą steruj ąc ą a komponentami wykonawczymi drukarki przedstawiono na rysunku 4.7

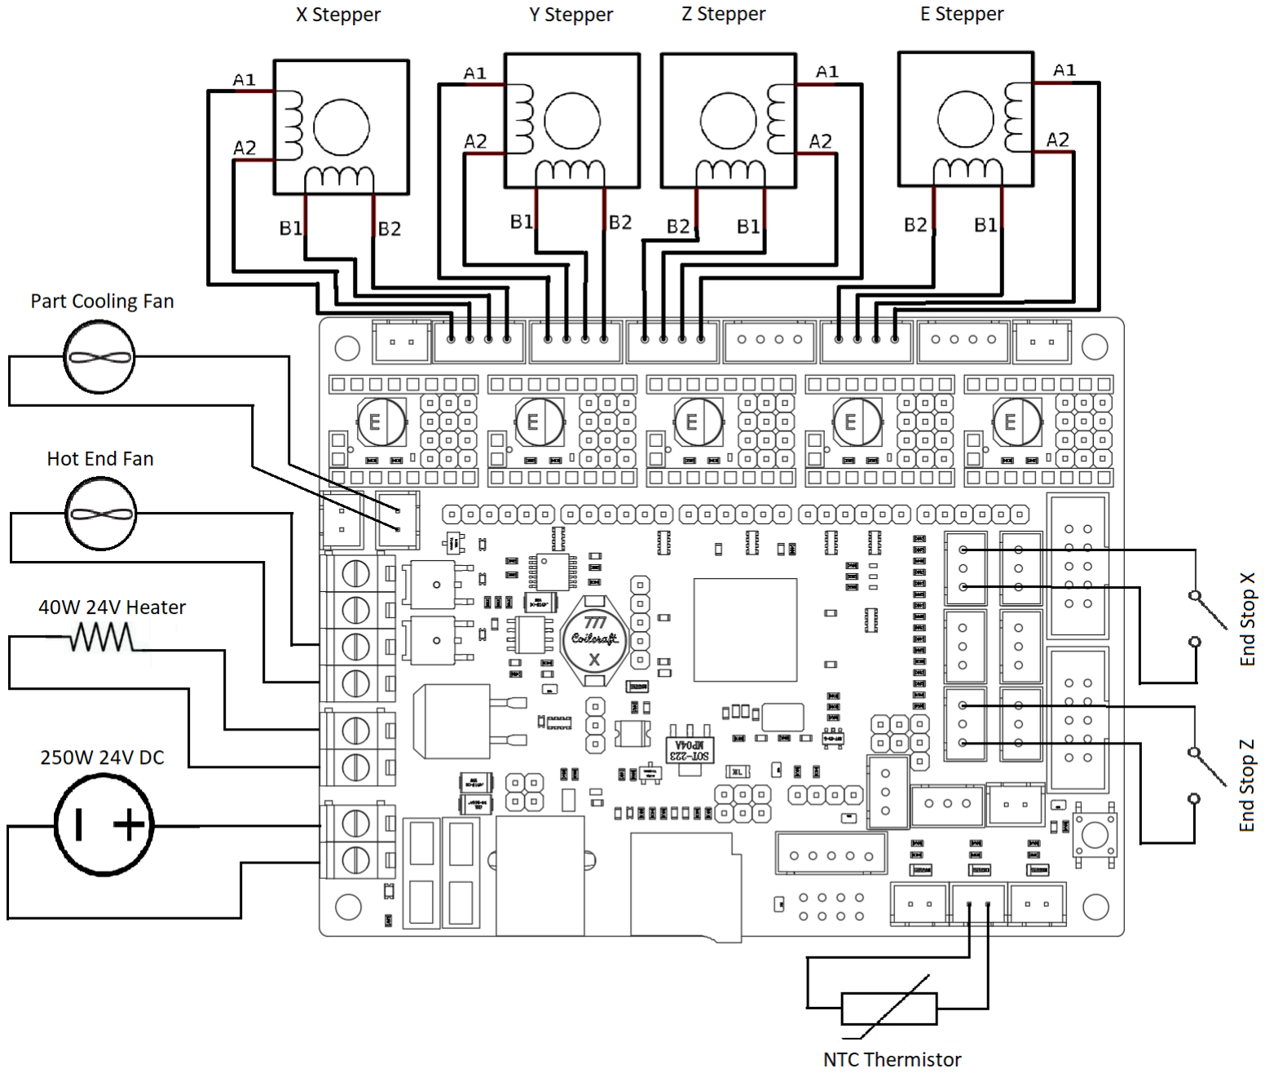
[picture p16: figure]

Rysunek 4.7: Schemat głowicy drukuj ącej

Grzałka kapsułowa ekstrudera podł ączona jest do wyjscia sterowanego PWM, oznaczo- ´ nego jako HE0 (ang. Heater Extruder 0), z termopar ą NTC 100k podł ączon ą do wejscia analogo- ´
wego TH0 (ang. Thermistor Heater 0). Przeł ączniki krancowe osi ´ | OX oraz osi OZ podł ączono do
odpowiednich wejsć X-STOP oraz Z-STOP. Zasilanie systemu realizowane jest z zewnętrznego ´ zasilacza impulsowego 24 V DC o mocy 250W. Regulacja temperatury odbywa się za pomoc ą regulatora PID (ang. Proportional-Integral-Derivative controller) zaimplementowanego w oprogramowaniu Marlin, który na podstawie odczytu temperatury z termopary moduluje moc dostarczan ą do grzałki poprzez sterowanie wypełnieniem sygnału PWM (ang. Pulse Width Modulation).

Płyta BTT SKR V1.4 Turbo posiada tylko jedno dedykowane wyjscie sterowane dla wen- ´ tylatora, które wykorzystywane jest przez wentylator chłodz ący wydruk, oznaczone jako FAN0. Brak drugiego dedykowanego wyjscia dla wentylatora chłodz ącego radiator przerwy grzewczej ´

heatbreak rozwi ązano podł ączaj ąc ten wentylator do portu HE1 (ang. Heater Extruder 1), standardowo przeznaczonego do zasilania drugiej grzałki ekstrudera w konfiguracjach z dwoma niezaleznymi ekstruderami. ˙

### 4.4. Implementacja oprogramowania Marlin

Implementacja kinematyki cylindrycznej w prototypie AL wymagała znacz ących modyfikacji konfiguracji oprogramowania steruj ącego w stosunku do standardowej konfiguracji drukarki kartezjan-´

skiej. Jako podstawę systemu sterowania wybrano open source firmware Marlin w wersji 2.1.2.5 [20], oferuj ące natywne wsparcie dla płyty BTT SKR V1.4 Turbo. Os´ OY realizuj ąca standardowo
przesuw liniowy w kierunku poprzecznym została przekształcona w os obrotow ą, umo ´ | zliwiaj ąc ą ˙
ci ągły obrót cylindrycznego bębna roboczego wokół osi OX, podczas gdy osie OX i OZ zachowuj ą charakter liniowy, realizuj ąc odpowiednio przesuw poprzeczny głowicy oraz ruch pionowy bramy.

Adaptacja oprogramowania Marlin dla współrzędnych biegunowych

Konfiguracja kinematyki polarnej w oprogramowaniu Marlin wymaga aktywacji dyrektywy preprocesora #define POLAR w pliku konfiguracyjnym Configuration.h oraz zdefiniowania osi obroto-
wych. Moduł POLAR domyslnie przystosowany jest do drukarek kartezja ´ | nskich z okr ągłym stołem ´
roboczym, ale zawarte w nim mechanizmy mozna wykorzysta ˙ | c w geometrii AL. Aktywacja modułu ´
POLAR wprowadza: dodatkowy tryb interpretacji współrzędnych jako k ąt obrotu wyrazony w stop- ˙ niach, narzędzia skalowania wartosci dedykowane do współrzędnych k ątowych, oraz dodatkowe ´
zabezpieczenia przed punktami osobliwosci w pobli ´ | zu osi obrotu. ˙

W przeciwienstwie do osi realizuj ących ruch liniowy, dla osi obrotowej w konfiguracji kine- ´

matyki polarnej nie istnieje wymaganie mechanicznego punktu odniesienia (ang. home position).
Poniewaz o ˙ s obrotowa realizuje ci ągły ruch (bez ogranicze ´ | n mechanicznych), punkt odniesienia ´
w postaci przeł ączników krancowych nie istnieje. Pozycja k ątowa jest wielko ´ | sci ą względn ą, a bę- ´
ben moze wykonywa ˙ | c wielokrotne pełne obroty w obu kierunkach bez ogranicze ´ | n. Ustawienie ´
Y_HOME_DIR = 0 sygnalizuje oprogramowaniu, ze o ˙ | s´ OY nie powinna byc bazowana podczas wy- ´
konywania komendy G28, co eliminuje wymóg obecnosci kra ´ | ncówki mechanicznej dla tej osi oraz ´

pozwala na pominięcie osi Y podczas sekwencji inicjalizacji systemu. W celu umozliwienia nie- ˙ ograniczonego obrotu bębna w obu kierunkach, konieczne było zdefiniowanie zakresów ruchu
osi OY jako praktycznie nieskonczonych poprzez ustawienie limitów programowych na warto ´ | sci ´

skrajne: Y_MIN_POS = −999 999 oraz Y_MAX_POS = 999 999.

Sterowniki TMC2208 skonfigurowano w tryb pracy z wykorzystaniem komunikacji UART. Konfiguracja sterowników polega na modyfikacji pliku Configuration_adv.h, który zawiera zaawansowane ustawienia oprogramowania, niedostępne w podstawowym pliku konfiguracyjnym. Tryb ten umozliwia programow ą kontrolę parametrów pracy silników krokowych, w tym dokład- ˙ nego ustawienia pr ądu referencyjnego ograniczaj ącego pr ąd w uzwojeniach silnika, oraz komunikację ze sterownikami, umozliwiaj ąc ą dokonywanie pomiarów oraz diagnostykę problemów. ˙

Uzyto trybu pracy ˙ | StealthChop, wprowadzaj ący wirtualizację mikrokrokowania, zapewniaj ąc ą ci-
ch ą pracę poprzez minimalizację oscylacji pr ądu w uzwojeniach. Tryb StealthChop automatycznie
dostosowuje wartosć pr ądu trzymaj ącego, co w konsekwencji umo ´ | zliwia zwiększenie efektyw- ˙
nego momentu trzymaj ącego bez ryzyka przepalenia uzwojen silnika czy kontrolera. ´

Jak wspomniano w poprzedniej sekcji, niestandardowe wykorzystanie portu HE1 (gniazdo drugiej grzałki ekstrudera) do sterowania wentylatorem chłodz ącym radiator przerwy grzewczej heatbreak wymaga redefinicji przypisania pinów wyjsciowych w konfiguracji oprogramowania. ´ W standardowej konfiguracji płyty BTT SKR V1.4 Turbo, port HE1 jest mapowany na pin mikro-
kontrolera P2_04 i domyslnie skonfigurowany jako wyj ´ | scie steruj ące grzałk ą. ´ | Zeby przekształci ˙ | c´

ten port w wyjscie steruj ące wentylatorem (FAN1), niezbędne jest wprowadzenie odpowiednich ´ dyrektyw preprocesora w pliku pins_BTT_SKR_V1_4.h, który zawiera definicje mapowania sprzętowego pinów dla danej płyty głównej.

Kalibracja parametrów pracy

Po skompilowaniu i wgraniu zmodyfikowanego oprogramowania na płytę steruj ąc ą BTT SKR 1.4 Turbo, niezbędne jest wykonanie następuj ących procedur kalibracyjnych: weryfikację i ustawienie prawidłowych kierunków obrotu silników krokowych, kalibrację wartosci kroków na jednostkę ´ przesunięcia dla wszystkich osi oraz ekstrudera, a takze dobór optymalnych parametrów regu- ˙ latora PID, utrzymuj ącego zadan ą temperaturę grzałki. Komunikację z drukark ą zrealizowano
za pomoc ą oprogramowania Pronterface [21] – graficznego interfejsu uzytkownika umo ˙ | zliwiaj ą- ˙
cego kontrolę drukarki poprzez nadawanie polecen G-code jak i monitorowanie stanu urz ądzenia ´ w czasie rzeczywistym za pomoc ą interfejsu USB (ang. Universal Serial Bus).

Podstawowa procedura kalibracji kroków na jednostkę przesunięcia polega na wydaniu komendy ruchu o znan ą wartosć, pomiarze uzyskanego przesunięcia i obliczeniu współczynnika ´ korekcyjnego, kompensuj ącego odchylenie rzeczywistego przesunięcia od wartosci teoretycznej. ´

Na przykładzie kalibracji osi obrotowej OY, w trybie pozycjonowania względnego (G91) wydano komendę G1 Y360 F600 - wykonanie obrotu o 360° z prędkosci ą posuwu k ątowego 600°/min. ´
Po zakonczeniu ruchu, niezgodno ´ | sci między zadeklarowanym k ątem obrotu (360°) a rzeczywi- ´
stym zmierzonym k ątem θm, wykorzystano do wyznaczenia współczynnika korekcyjnego zgodnie z relacj ą:
| stepsnew = stepsold ×

360°

θm

,

gdzie θm oznacza rzeczywisty zmierzony k ąt obrotu bębna. Skorygowana wartosć kroków jest ´

przesyłana do płytki za pomoc ą komendy konfiguracyjnej M92 Y[wartość] i trwale zapisywana w pamięci EEPROM płyty steruj ącej poleceniem M500. Analogiczn ą metodologię zastosowano dla kalibracji osi liniowych OX i OZ, i ekstrudera, w którym obiektem pomiaru był odcinek filamentu wci ągnięty do ekstrudera.

Zadaniem regulatora PID jest utrzymanie stałej temperatury grzałki ekstrudera z mozliwie ˙
jak najmniejszymi oscylacjami uchybu sterowania. Strojenie rozpoczęto od domyslnych warto ´ | sci ´
parametrów regulatora dla grzałki kapsułowej z termpoar ą NTC 100K: Kp | = 22,2; Ki | = 1,08;
Kd = 114. Następnie uruchomiono procedurę automatycznego strojenia regulatora (ang. PID autotuning) za pomoc ą komendy M303 E0 S210 C5, która nakazuje wykonanie pięciu cykli nagrzewania i stygnięcia grzałki z temperatur ą docelow ą 210°C. Algorytm automatycznego strojenia analizuje dynamikę termiczn ą układu grzewczego poprzez pomiar czasów nagrzewania, warto-
sci maksymalnego przeregulowania, szybko ´ | sci stygnięcia oraz amplitudy oscylacji temperatury. ´

Na podstawie zebranych danych, za pomoc ą metody Zieglera-Nicholsa, wyznaczane s ą wartosci ´ współczynników Kp, Ki oraz Kd.
Po zakonczeniu procedury ´ | PID autotuning uzyskane parametry regulatora Kp = 27,65;
Ki = 2,50; Kd = 76, 35 zapisano w EEPROM za pomoc ą polecenia M301 P9.25 I0.41 D52.70. Główn ą widoczn ą zmian ą parametrów jest znacz ący wzrost wzmocnienia członu całkuj ącego, które pomogło w eliminacji błędu ustalonego. Odpowiedź skokowa układu nie posiada przeregulowania ani oscylacji, czas ustalania do zadanej temperatury 210°Cwynosi 2 minuty 27 sekund.
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

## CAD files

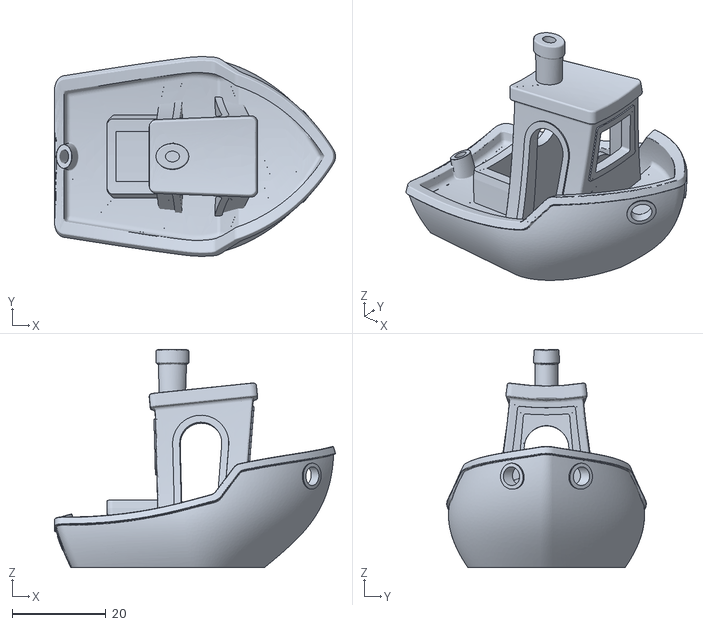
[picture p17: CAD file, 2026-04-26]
Cura Slicer to cylindrical conversion/sample gcode/3DBenchyCut_flattened_decimated.stl
60.0 x 42.6 x 46.6

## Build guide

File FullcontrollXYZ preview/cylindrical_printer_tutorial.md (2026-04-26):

```python
import plotly.io as pio
pio.renderers.default = 'png'
```

# Cylindrical 3D Printer Tutorial

This tutorial demonstrates how to create G-code paths for a printer with lathe geometry.

## Coordinate System

Printer uses a unique coordinate system where:

- **X**: Linear position along the rotation axis (mm)
- **Y**: Rotation angle in degrees (rotates around X-axis)  
- **Z**: Height above the drum surface (mm)
- **E**: Extruder (mm)

## G-code Format
```gcode
G1 X10.000 Y10.0000 Z10.000 E10.00000 F3000
```

## Import FullControl and Cylindrical Functions

```python
import fullcontrol as fc
from fullcontrol.geometry.cylindrical import (
    cylindrical_to_point,
    cylindrical_line,
    cylindrical_arc,
    cylindrical_circle,
    cylindrical_helix,
    cylindrical_spiral,
    cylindrical_wave,
    cylindrical_to_cartesian,
    convert_steps_for_visualization
)
from math import tau, sin, cos
```

```python
import plotly.graph_objects as go
import numpy as np

def plot_cylindrical_with_correct_aspect(viz_steps, title='3D Toolpath', margin_percent=30, zoom=1.0, width=1200, height=720):
    """
    Plot visualization steps with proper cylindrical aspect ratio and margins.
    """

    plot_data = fc.transform(viz_steps, 'plot', fc.PlotControls(raw_data=True))
    fig = go.Figure()
    
    total_print_points = 0
    for path in plot_data.paths:
        if path.extruder.on:
            total_print_points += len(path.xvals)
    
    current_point = 0
    for path in plot_data.paths:
        if path.extruder.on:
            # Printing path - create continuous gradient from blue to cyan
            num_points = len(path.xvals)
            
            if total_print_points > 1 and num_points > 1:
                color_values = []
                for i in range(num_points):
                    progress = (current_point + i) / (total_print_points - 1)
                    color_values.append(progress)
                
                current_point += num_points
                
                fig.add_trace(go.Scatter3d(
                    mode='lines',
                    x=path.xvals,
                    y=path.yvals,
                    z=path.zvals,
                    line=dict(
                        color=color_values,
                        colorscale=[[0, 'rgb(0,150,255)'], [1, 'rgb(0,255,255)']],
                        width=3,
                        showscale=False
                    ),
                    showlegend=False,
                    hoverinfo='skip'
                ))
            else:
                fig.add_trace(go.Scatter3d(
                    mode='lines',
                    x=path.xvals,
                    y=path.yvals,
                    z=path.zvals,
                    line=dict(color='rgb(0,150,255)', width=3),
                    showlegend=False,
                    hoverinfo='skip'
                ))
        else:
            # Travel path - dark red
            fig.add_trace(go.Scatter3d(
                mode='lines',
                x=path.xvals,
                y=path.yvals,
                z=path.zvals,
                line=dict(color='rgb(150,0,0)', width=1),
                showlegend=False,
                hoverinfo='skip'
            ))
    
    # Calculate aspect ratio for cylindrical coordinates
    all_x = [val for path in plot_data.paths if len(path.xvals) > 0 for val in path.xvals]
    all_y = [val for path in plot_data.paths if len(path.yvals) > 0 for val in path.yvals]
    all_z = [val for path in plot_data.paths if len(path.zvals) > 0 for val in path.zvals]
    
    if not all_x or not all_y or not all_z:
        print("Warning: No data to plot")
        return fig
    
    x_range = max(all_x) - min(all_x) if all_x else 1
    y_range = max(all_y) - min(all_y) if all_y else 1
    z_range = max(all_z) - min(all_z) if all_z else 1

    margin = margin_percent / 100.0
    x_range_with_margin = x_range * (1 + margin)
    y_range_with_margin = y_range * (1 + margin)
    z_range_with_margin = z_range * (1 + margin)
    max_yz_range = max(y_range_with_margin, z_range_with_margin)
    
    x_center = (max(all_x) + min(all_x)) / 2
    y_center = (max(all_y) + min(all_y)) / 2
    z_center = (max(all_z) + min(all_z)) / 2
    
    zoom_factor = 1.0 / zoom if zoom > 0 else 1.0
    x_range_zoomed = x_range_with_margin * zoom_factor
    yz_range_zoomed = max_yz_range * zoom_factor
    
    aspect_x = x_range_zoomed / yz_range_zoomed if yz_range_zoomed > 0 else 1
    aspect_y = 1
    aspect_z = 1
    
    fig.update_layout(
        width=width,
        height=height,
        scene=dict(
            aspectmode='manual',
            aspectratio=dict(x=aspect_x, y=aspect_y, z=aspect_z),
            xaxis=dict(
                title='X (mm)', 
                range=[x_center - x_range_zoomed/2, x_center + x_range_zoomed/2]
            ),
            yaxis=dict(
                title='Y (mm)', 
                range=[y_center - yz_range_zoomed/2, y_center + yz_range_zoomed/2]
            ),
            zaxis=dict(
                title='Z (mm)', 
                range=[z_center - yz_range_zoomed/2, z_center + yz_range_zoomed/2]
            ),
        ),
        template='plotly_dark',
        showlegend=False,
        title=title
    )
    
    return fig
```

## Example 1: Simple Circle at Fixed X Position

Create a circle by rotating around the X-axis at a fixed radial distance.

```python
# Printer configuration
DRUM_DIAMETER = 56  #mm
LAYER_HEIGHT = 0.2  #mm
EXTRUSION_WIDTH = 0.4  # mm (nozzle diameter)
FLOW_PERCENT = 100     # %

#Move to starting position
steps = []
steps.append(fc.Extruder(on=False))
steps.append(cylindrical_to_point(x=50, theta_degrees=0, radius=LAYER_HEIGHT))
steps.append(fc.Extruder(on=True))

# Create circle at first layer height
circle_points = cylindrical_circle(x=50, radius=LAYER_HEIGHT, theta_start_degrees=0, segments=64)
steps.extend(circle_points)

# Visualization
viz_steps = convert_steps_for_visualization(steps, drum_diameter=DRUM_DIAMETER)
plot_cylindrical_with_correct_aspect(viz_steps, title='Simple Circle').show()

# Generate G-code
gcode = fc.transform(steps, 'gcode', fc.GcodeControls(
    printer_name='cylindrical',
    save_as='simple_circle',
    initialization_data={
        'drum_radius': DRUM_DIAMETER / 2,
        'extrusion_width': EXTRUSION_WIDTH,
        'extrusion_height': LAYER_HEIGHT,
        'material_flow_percent': FLOW_PERCENT,
        'nozzle_temp': 210,
        'fan_percent': 100,
        'print_speed': 1000
    }
))
```

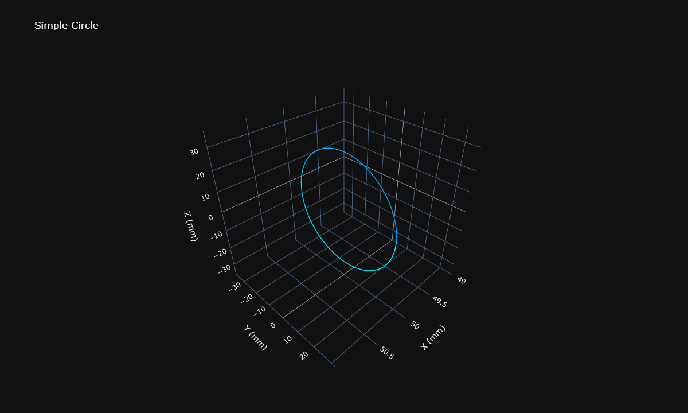
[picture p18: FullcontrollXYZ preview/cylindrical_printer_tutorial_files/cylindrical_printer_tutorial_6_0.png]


## Example 2: Helical Path Along X-Axis

Create a helix by moving along the X-axis while rotating.

```python
# Printer configuration
DRUM_DIAMETER = 56  #mm
LAYER_HEIGHT = 0.2  #mm
EXTRUSION_WIDTH = 0.4  # mm (nozzle diameter)
FLOW_PERCENT = 100     # %

#Move to starting position
steps = []
steps.append(fc.Extruder(on=False))
steps.append(cylindrical_to_point(x=10, theta_degrees=0, radius=LAYER_HEIGHT))
steps.append(fc.Extruder(on=True))

# Create helix
helix_points = cylindrical_helix(
    x_start=10,
    x_end=100,
    radius=LAYER_HEIGHT,
    theta_start_degrees=0,
    turns=5.0,
    segments=200,
    clockwise=False
)
steps.extend(helix_points)

# Visualization
viz_steps = convert_steps_for_visualization(steps, drum_diameter=DRUM_DIAMETER)
plot_cylindrical_with_correct_aspect(viz_steps, title='Helical Path').show()

# Generate G-code
gcode = fc.transform(steps, 'gcode', fc.GcodeControls(
    printer_name='cylindrical',
    save_as='helix',
    initialization_data={
        'drum_radius': DRUM_DIAMETER / 2,
        'extrusion_width': EXTRUSION_WIDTH,
        'extrusion_height': LAYER_HEIGHT,
        'material_flow_percent': FLOW_PERCENT,
        'nozzle_temp': 210,
        'fan_percent': 100,
        'print_speed': 1000
    }
))
```

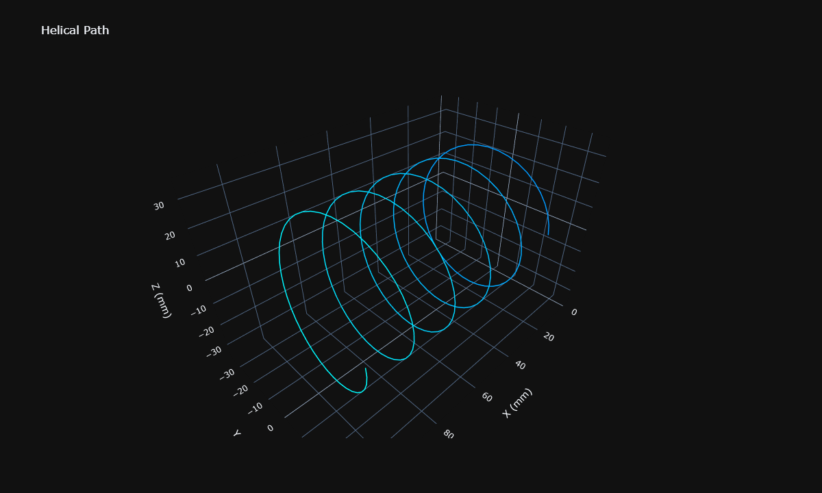
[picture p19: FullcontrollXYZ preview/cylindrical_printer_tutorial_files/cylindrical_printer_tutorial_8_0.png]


## Example 3: Spiral (Varying Radius)

Create a spiral at a fixed X position with changing radius.

```python
# Printer configuration
DRUM_DIAMETER = 56  #mm
LAYER_HEIGHT = 0.2  #mm
EXTRUSION_WIDTH = 0.4  # mm (nozzle diameter)
FLOW_PERCENT = 100     # %

#Move to starting position
steps = []
num_layers = 50
steps.append(fc.Extruder(on=False))
steps.append(cylindrical_to_point(x=50, theta_degrees=0, radius=LAYER_HEIGHT))
steps.append(fc.Extruder(on=True))

# Create spiral
spiral_points = cylindrical_spiral(
    x=50,
    radius_start=LAYER_HEIGHT,
    radius_end=num_layers * LAYER_HEIGHT,
    theta_start_degrees=0,
    turns=3.0,
    segments=150,
    clockwise=False
)
steps.extend(spiral_points)

# Visualization
viz_steps = convert_steps_for_visualization(steps, drum_diameter=DRUM_DIAMETER)
plot_cylindrical_with_correct_aspect(viz_steps, title='Spiral').show()

# Generate G-code
gcode = fc.transform(steps, 'gcode', fc.GcodeControls(
    printer_name='cylindrical',
    save_as='spiral',
    initialization_data={
        'drum_radius': DRUM_DIAMETER / 2,
        'extrusion_width': EXTRUSION_WIDTH,
        'extrusion_height': LAYER_HEIGHT,
        'material_flow_percent': FLOW_PERCENT,
        'nozzle_temp': 210,
        'fan_percent': 100,
        'print_speed': 1000
    }
))
```

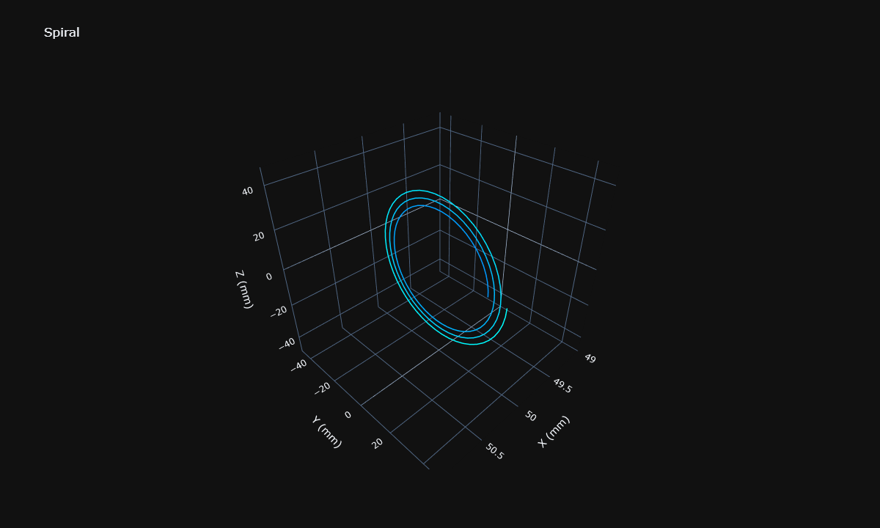
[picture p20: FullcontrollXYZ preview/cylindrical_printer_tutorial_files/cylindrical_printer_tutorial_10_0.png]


## Example 4: Multiple Circles at Different X Positions (Cylinder)

Create a cylinder by stacking circles along the X-axis.

```python
# Printer configuration
DRUM_DIAMETER = 56  #mm
LAYER_HEIGHT = 0.2  #mm
EXTRUSION_WIDTH = 0.4  # mm (nozzle diameter)
FLOW_PERCENT = 100     # %

# Parameters
x_start = 20
layers = 200
x_spacing = EXTRUSION_WIDTH  # Lines 0.4mm apart

#Move to starting position
steps = []
steps.append(fc.Extruder(on=False))
steps.append(cylindrical_to_point(x=x_start, theta_degrees=0, radius=LAYER_HEIGHT))
steps.append(fc.Extruder(on=True))

# Create cylinder layers - all same diameter, offset in X
current_angle = 0
for layer in range(layers):
    x_pos = x_start + layer * x_spacing
    z_height = LAYER_HEIGHT  # Same radius for all layers
    circle = cylindrical_circle(x=x_pos, radius=z_height, theta_start_degrees=current_angle, segments=64)
    steps.extend(circle)
    current_angle += 360

# Visualization
viz_steps = convert_steps_for_visualization(steps, drum_diameter=DRUM_DIAMETER)
plot_cylindrical_with_correct_aspect(viz_steps, title='Cylinder').show()

# Generate G-code
gcode = fc.transform(steps, 'gcode', fc.GcodeControls(
    printer_name='cylindrical',
    save_as='cylinder',
    initialization_data={
        'drum_radius': DRUM_DIAMETER / 2,
        'extrusion_width': EXTRUSION_WIDTH,
        'extrusion_height': LAYER_HEIGHT,
        'material_flow_percent': FLOW_PERCENT,
        'nozzle_temp': 210,
        'fan_percent': 100,
        'print_speed': 1000
    }
))
```

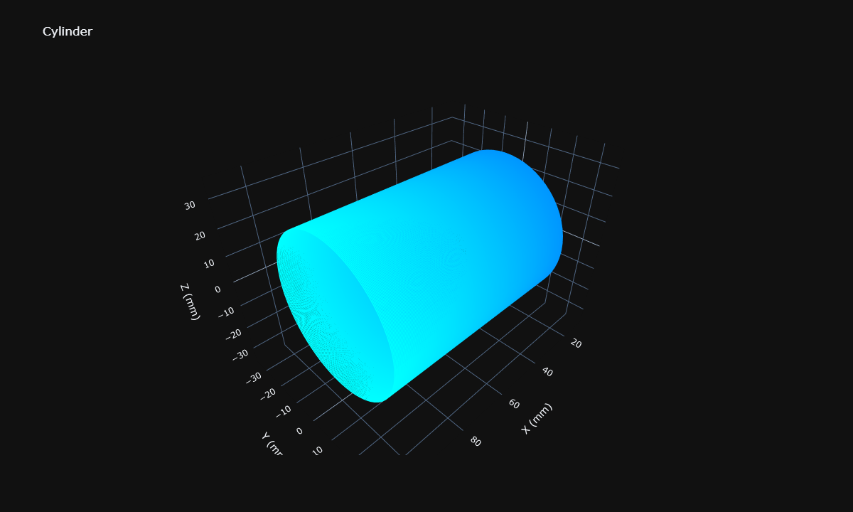
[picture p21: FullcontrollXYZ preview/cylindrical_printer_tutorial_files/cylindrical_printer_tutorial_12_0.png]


## Example 5: Cone (Varying Radius with X Position)

```python
# Printer configuration
DRUM_DIAMETER = 56  #mm
LAYER_HEIGHT = 0.2  #mm
EXTRUSION_WIDTH = 0.4  # mm (nozzle diameter)
FLOW_PERCENT = 100     # %

# Parameters
x_start = 20
x_end = 100
layers = 20
layer_height_x = (x_end - x_start) / layers
z_max = 10

#Move to starting position
steps = []
steps.append(fc.Extruder(on=False))
steps.append(cylindrical_to_point(x=x_start, theta_degrees=0, radius=LAYER_HEIGHT))
steps.append(fc.Extruder(on=True))

# Create cone layers
current_angle = 0
for layer in range(layers):
    t = layer / (layers - 1)
    x_pos = x_start + t * (x_end - x_start)
    z_height = LAYER_HEIGHT + t * (z_max - LAYER_HEIGHT)
    circle = cylindrical_circle(x=x_pos, radius=z_height, theta_start_degrees=current_angle, segments=64)
    steps.extend(circle)
    current_angle += 360

# Visualization
viz_steps = convert_steps_for_visualization(steps, drum_diameter=DRUM_DIAMETER)
plot_cylindrical_with_correct_aspect(viz_steps, title='Cone', zoom=0.7).show()

# Generate G-code
gcode = fc.transform(steps, 'gcode', fc.GcodeControls(
    printer_name='cylindrical',
    save_as='cone',
    initialization_data={
        'drum_radius': DRUM_DIAMETER / 2,
        'extrusion_width': EXTRUSION_WIDTH,
        'extrusion_height': LAYER_HEIGHT,
        'material_flow_percent': FLOW_PERCENT,
        'nozzle_temp': 210,
        'fan_percent': 100,
        'print_speed': 1000
    }
))
```

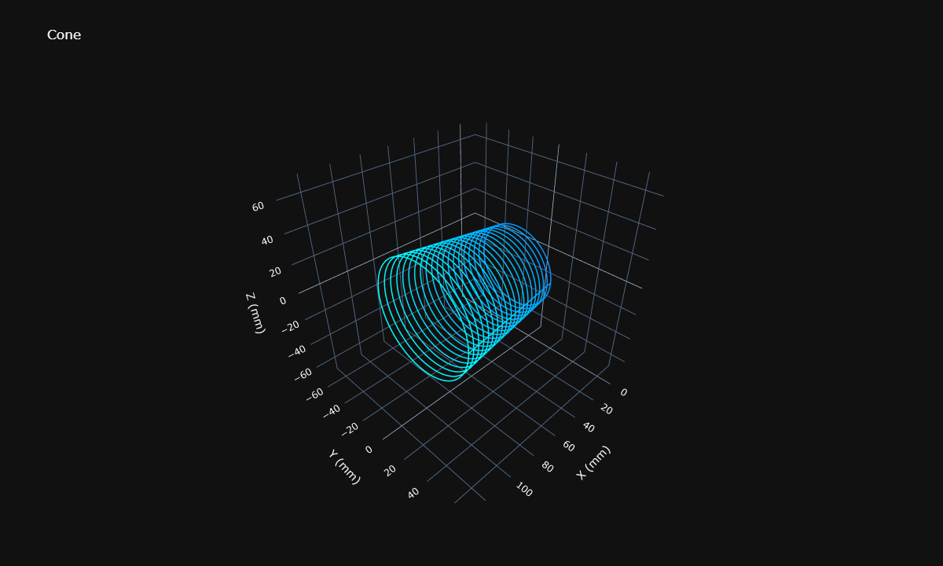
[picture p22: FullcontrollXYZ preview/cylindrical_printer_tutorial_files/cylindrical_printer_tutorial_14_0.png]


## Example 6: Wave Pattern

```python
# Printer configuration
DRUM_DIAMETER = 56  #mm
LAYER_HEIGHT = 0.2  #mm
EXTRUSION_WIDTH = 0.4  # mm (nozzle diameter)
FLOW_PERCENT = 100     # %

#Move to starting position
steps = []
steps.append(fc.Extruder(on=False))
steps.append(cylindrical_to_point(x=10, theta_degrees=0, radius=15, z_offset=0))
steps.append(fc.Extruder(on=True))

# Create wave pattern
wave_points = cylindrical_wave(
    x_start=10,
    x_end=100,
    radius=15,
    theta_start_degrees=0,
    wave_amplitude_degrees=30,
    wave_frequency=5,
    segments=200,
    z_offset=0
)
steps.extend(wave_points)

# Visualization
viz_steps = convert_steps_for_visualization(steps, drum_diameter=DRUM_DIAMETER)
plot_cylindrical_with_correct_aspect(viz_steps, title='Wave Pattern').show()

# Generate G-code
gcode = fc.transform(steps, 'gcode', fc.GcodeControls(
    printer_name='cylindrical',
    save_as='wave',
    initialization_data={
        'drum_radius': DRUM_DIAMETER / 2,
        'extrusion_width': EXTRUSION_WIDTH,
        'extrusion_height': LAYER_HEIGHT,
        'material_flow_percent': FLOW_PERCENT,
        'nozzle_temp': 210,
        'fan_percent': 100,
        'print_speed': 1000
    }
))
```

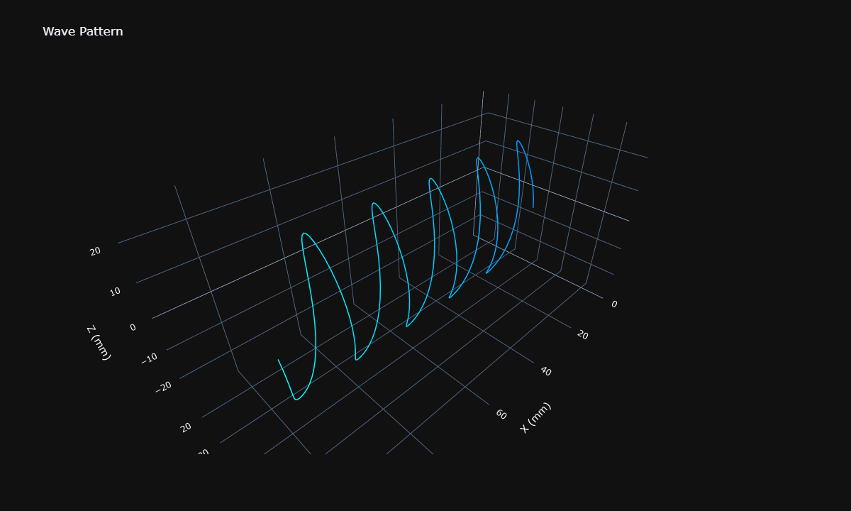
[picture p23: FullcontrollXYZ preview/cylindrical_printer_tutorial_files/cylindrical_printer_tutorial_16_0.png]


## Example 8: Spring (Helix with Increasing Radius)

Create a spring with 10 turns and 10 layers of thickness.

## Advanced: Custom Design Function

Create a reusable function for common cylindrical shapes.

```python
# Printer configuration
DRUM_DIAMETER = 56  #mm
LAYER_HEIGHT = 0.2  #mm
EXTRUSION_WIDTH = 0.4  # mm (nozzle diameter)
FLOW_PERCENT = 100     # %
LINE_OVERLAP_PERCENT = 10  # % overlap between adjacent lines for better adhesion

# Spring parameters
x_start = 20
turns = 5  # Number of complete rotations
wire_layers_wide = 10  # Wire thickness along helix (X direction)
wire_layers_thick = 15  # Wire thickness radially (Z direction) - 15 layers tall

# Layer offset for strength
layer_offset = 0.1  # Offset alternating radial layers by ±0.1mm for better bonding

# Calculate line spacing with overlap
line_spacing = EXTRUSION_WIDTH * (1 - LINE_OVERLAP_PERCENT / 100)  # 0.4 * 0.9 = 0.36mm

# Calculate wire width and pitch
wire_width = (wire_layers_wide - 1) * line_spacing + EXTRUSION_WIDTH  # 9*0.36 + 0.4 = 3.64mm
gap_width = 10 * line_spacing  # 10 * 0.36 = 3.6mm for 4mm equivalent
pitch = wire_width + gap_width  # 3.64 + 3.6 = 7.24mm per turn
x_length = turns * pitch  # 5 * 7.24mm = 36.2mm total length

print(f"Line spacing (with {LINE_OVERLAP_PERCENT}% overlap): {line_spacing:.3f}mm")
print(f"Wire width: {wire_width:.3f}mm")
print(f"Gap width: {gap_width:.3f}mm")
print(f"Pitch per turn: {pitch:.3f}mm")
print(f"Total spring length: {x_length:.3f}mm")
print(f"Wire thickness (radial): {wire_layers_thick * LAYER_HEIGHT:.1f}mm")
print(f"Layer offset: ±{layer_offset}mm for alternating radial layers (brick pattern)")

steps = []
steps.append(fc.Extruder(on=False))
steps.append(cylindrical_to_point(x=x_start, theta_degrees=0, radius=LAYER_HEIGHT))
steps.append(fc.Extruder(on=True))

# Create spring with alternating helix directions to minimize travel
helix_count = 0
for z_layer in range(wire_layers_thick):
    # Offset alternating radial layers by ±0.1mm for better interlocking (brick pattern)
    x_radial_offset = layer_offset if z_layer % 2 == 1 else -layer_offset
    
    for x_layer in range(wire_layers_wide):
        current_radius = LAYER_HEIGHT + (z_layer * LAYER_HEIGHT)
        x_offset = x_layer * line_spacing + x_radial_offset  # Add brick layer offset
        
        # Alternate direction for each helix to minimize travel moves
        reverse = (helix_count % 2 == 1)
        
        if reverse:
            # Going backwards (right to left)
            helix_start_x = x_start + x_offset + x_length
            helix_end_x = x_start + x_offset
            helix_start_theta = turns * 360
            helix_turns = -turns
        else:
            # Going forwards (left to right)
            helix_start_x = x_start + x_offset
            helix_end_x = x_start + x_offset + x_length
            helix_start_theta = 0
            helix_turns = turns
        
        # Move to start of this pass (only if not the very first pass)
        if helix_count > 0:
            steps.append(fc.Extruder(on=False))
            steps.append(cylindrical_to_point(x=helix_start_x, theta_degrees=helix_start_theta, radius=current_radius))
            steps.append(fc.Extruder(on=True))
        
        # Create helix for this pass
        helix = cylindrical_helix(
            x_start=helix_start_x,
            x_end=helix_end_x,
            radius=current_radius,
            theta_start_degrees=helix_start_theta,
            turns=helix_turns,
            segments=turns * 16,
            clockwise=False
        )
        steps.extend(helix)
        helix_count += 1

# Visualization
viz_steps = convert_steps_for_visualization(steps, drum_diameter=DRUM_DIAMETER)
plot_cylindrical_with_correct_aspect(viz_steps, title='Spring').show()

# Generate G-code
gcode = fc.transform(steps, 'gcode', fc.GcodeControls(
    printer_name='cylindrical',
    save_as='spring',
    initialization_data={
        'drum_radius': DRUM_DIAMETER / 2,
        'extrusion_width': EXTRUSION_WIDTH,
        'extrusion_height': LAYER_HEIGHT,
        'material_flow_percent': FLOW_PERCENT,
        'nozzle_temp': 210,
        'fan_percent': 100,
        'print_speed': 1000
    }
))
```

    Line spacing (with 10% overlap): 0.360mm
    Wire width: 3.640mm
    Gap width: 3.600mm
    Pitch per turn: 7.240mm
    Total spring length: 36.200mm
    Wire thickness (radial): 3.0mm
    Layer offset: ±0.1mm for alternating radial layers (brick pattern)

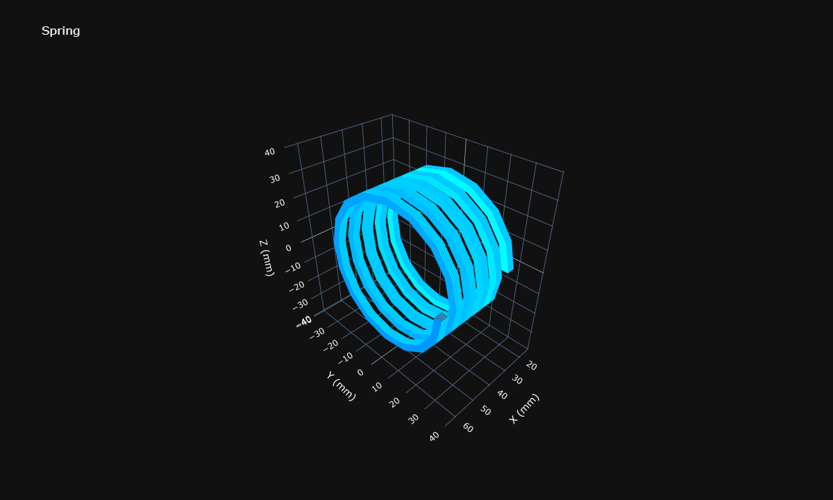
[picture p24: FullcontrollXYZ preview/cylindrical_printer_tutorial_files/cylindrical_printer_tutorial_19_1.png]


## Example: Wavy Bracelet

Create a bracelet with a sinusoidal wave pattern around the circumference. Layers stack radially outward from the drum surface.

```python
# Printer configuration
DRUM_DIAMETER = 56  #mm
LAYER_HEIGHT = 0.2  #mm
EXTRUSION_WIDTH = 0.4  # mm (nozzle diameter)
FLOW_PERCENT = 100     # %

def create_cylindrical_vase(x_start, x_end, z_start, z_end, layers, segments_per_layer=64):
    steps = []
    steps.append(fc.Extruder(on=False))
    steps.append(cylindrical_to_point(x=x_start, theta_degrees=0, radius=z_start))
    steps.append(fc.Extruder(on=True))
    
    current_angle = 0
    for layer in range(layers):
        t = layer / (layers - 1) if layers > 1 else 0
        x_pos = x_start + t * (x_end - x_start)
        z_height = z_start + t * (z_end - z_start)
        z_height += 2 * sin(t * tau * 3)
        
        circle = cylindrical_circle(
            x=x_pos,
            radius=z_height,
            theta_start_degrees=current_angle,
            segments=segments_per_layer
        )
        steps.extend(circle)
        current_angle += 360
    
    return steps

# Create vase
vase_steps = create_cylindrical_vase(
    x_start=10,
    x_end=100,
    z_start=LAYER_HEIGHT,
    z_end=10,
    layers=50
)

# Visualization
viz_steps = convert_steps_for_visualization(vase_steps, drum_diameter=DRUM_DIAMETER)
plot_cylindrical_with_correct_aspect(viz_steps, title='Cylindrical Vase', zoom=0.6).show()

# Generate G-code
gcode = fc.transform(vase_steps, 'gcode', fc.GcodeControls(
    printer_name='cylindrical',
    save_as='cylindrical_vase',
    initialization_data={
        'drum_radius': DRUM_DIAMETER / 2,
        'extrusion_width': EXTRUSION_WIDTH,
        'extrusion_height': LAYER_HEIGHT,
        'material_flow_percent': FLOW_PERCENT,
        'nozzle_temp': 210,
        'fan_percent': 100,
        'print_speed': 1000
    }
))
```

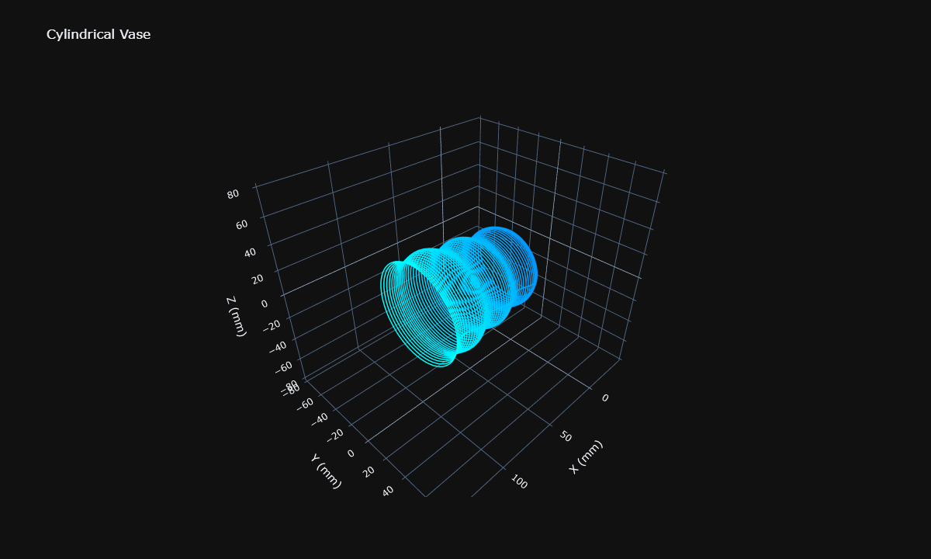
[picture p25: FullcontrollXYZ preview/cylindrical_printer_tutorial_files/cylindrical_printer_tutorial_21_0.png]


```python
# Printer configuration
DRUM_DIAMETER = 56  #mm
LAYER_HEIGHT = 0.2  #mm
EXTRUSION_WIDTH = 0.4  # mm (nozzle diameter)
FLOW_PERCENT = 100     # %

# Bracelet parameters
x_center = 50  # Center position along X axis
bracelet_width = 5  # Width/thickness of bracelet in mm (along X axis)
num_radial_layers = 10  # Number of layers stacking radially outward

# Wave parameters
wave_amplitude = 5  # How much the bracelet waves along X axis (mm)
wave_frequency = 4  # Number of complete waves around the bracelet

# Layer offset for strength
layer_offset = 0.1  # Offset alternating layers by ±0.1mm for better bonding

# Calculate number of circles needed for bracelet width
num_width_circles = max(1, int(bracelet_width / EXTRUSION_WIDTH))

print(f"Creating bracelet with {num_radial_layers} radial layers")
print(f"Bracelet width: {bracelet_width}mm ({num_width_circles} circles wide)")
print(f"Wave amplitude: {wave_amplitude}mm along X axis")
print(f"Wave frequency: {wave_frequency} waves around circumference")
print(f"Layer offset: ±{layer_offset}mm for alternating layers")
print(f"Alternating circle directions to minimize travel moves")

steps = []
steps.append(fc.Extruder(on=False))
steps.append(cylindrical_to_point(x=x_center, theta_degrees=0, radius=LAYER_HEIGHT))
steps.append(fc.Extruder(on=True))

# Create wavy bracelet - layers stack radially outward
circle_count = 0
for radial_layer in range(num_radial_layers):
    # Radius is CONSTANT for this entire layer - only increases between layers
    current_radius = LAYER_HEIGHT + radial_layer * LAYER_HEIGHT
    
    # Offset alternating layers by ±0.1mm for better interlocking
    x_layer_offset = layer_offset if radial_layer % 2 == 1 else -layer_offset
    
    # Create multiple circles at this radial height to give bracelet width/thickness
    for width_idx in range(num_width_circles):
        # Base X position for this width layer
        x_base = x_center - bracelet_width/2 + width_idx * EXTRUSION_WIDTH + x_layer_offset
        
        # Alternate direction for each circle to minimize travel moves
        reverse = (circle_count % 2 == 1)
        
        # Create a circle at this radius and X position, varying X to create wave
        segments = 128  # High resolution for smooth waves
        
        for i in range(segments + 1):
            if reverse:
                # Go backwards (360 to 0)
                theta = 360 - (360 * i / segments)
            else:
                # Go forwards (0 to 360)
                theta = (360 * i / segments)
            
            theta_rad = theta * (tau / 360)
            
            # Vary X position sinusoidally as we go around - this creates the wave!
            x_variation = wave_amplitude * sin(wave_frequency * theta_rad)
            x_pos = x_base + x_variation
            
            point = cylindrical_to_point(x=x_pos, theta_degrees=theta, radius=current_radius)
            steps.append(point)
        
        circle_count += 1

# Visualization
viz_steps = convert_steps_for_visualization(steps, drum_diameter=DRUM_DIAMETER)
plot_cylindrical_with_correct_aspect(viz_steps, title='Wavy Bracelet', zoom=0.7).show()

# Generate G-code
gcode = fc.transform(steps, 'gcode', fc.GcodeControls(
    printer_name='cylindrical',
    save_as='wavy_bracelet',
    initialization_data={
        'drum_radius': DRUM_DIAMETER / 2,
        'extrusion_width': EXTRUSION_WIDTH,
        'extrusion_height': LAYER_HEIGHT,
        'material_flow_percent': FLOW_PERCENT,
        'nozzle_temp': 210,
        'fan_percent': 100,
        'print_speed': 1000
    }
))
```

    Creating bracelet with 10 radial layers
    Bracelet width: 5mm (12 circles wide)
    Wave amplitude: 5mm along X axis
    Wave frequency: 4 waves around circumference
    Layer offset: ±0.1mm for alternating layers
    Alternating circle directions to minimize travel moves

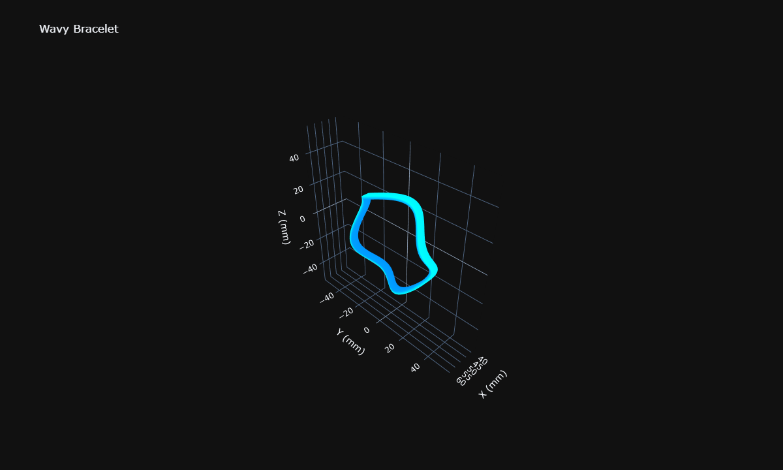
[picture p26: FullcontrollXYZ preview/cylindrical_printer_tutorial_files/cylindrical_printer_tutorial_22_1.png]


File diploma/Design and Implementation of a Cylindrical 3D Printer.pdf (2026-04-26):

### Student name: Grzegorz Lange

### Student ID: 190906

### Level of study: first-cycle studies

### Form of study: full-time

### Field of study: Automation, Cybernetics and Robotics

### Profile: Decision Systems and Robotics

## ENGINEERING DIPLOMA PROJECT

### Project title in Polish: Projekt i implementacja cylindrycznej drukarki 3D

### Project title in English: Design and Implementation of a Custom Cylindrical 3D

### Printer

### Project supervisor: dr inz. Piotr Fiertek ˙

Translated by Gemini 3.1 Pro (Preview)

### ABSTRACT

This work presents a cylindrical FDM printer prototype along with tool path generation methodology for cylindrical kinematics. Cylindrical kinematics expands the range of geometries available for Cartesian 3D printing to include rotationally symmetric components, helical structures, and lathe-like products with internal geometry. The cylindrical coordinate system allows for tool orientation that eliminates the need for support structures for a wide range of components. Continuous rotation of the working drum enables continuity of extrusion trajectories along the rotational axis, leading to material properties approaching isotropic behavior.
This work presents three approaches to path generation: adaptation of existing Cartesian slicers with mathematical correction of geometric distortions and extrusion parameters; extension of the FullControl GCode Designer environment enabling direct generation of simple geometries described by mathematical functions; prototype implementation of a cylindrical slicer enabling tool path generation from STL models, incorporating perimeter wall parameters and rectilinear infill. Prototype tests confirmed the feasibility of springs, screws, and other rotational geometries without the need for support structures.

Keywords: cylindrical printer, additive manufacturing, tool path generation, support structure elimination
Field of science and technology: Mechanical Engineering, Automation and Robotics

### CONTENTS

ABSTRACT | 3
TABLE OF CONTENTS | 5
LIST OF IMPORTANT SYMBOLS AND ABBREVIATIONS | 6
1 INTRODUCTION | 8
2 LITERATURE REVIEW | 11
3 MATHEMATICAL FOUNDATIONS | 14
4 SYSTEM DESIGN AND ARCHITECTURE | 21

5 MANUFACTURING CAPABILITIES AND APPLICATIONS | 31
6 PATH GENERATION | 38
7 RESULTS AND DISCUSSION | 51
LIST OF FIGURES | 53
LIST OF TABLES | 54
BIBLIOGRAPHY | 57

### LIST OF IMPORTANT SYMBOLS AND ABBREVIATIONS

ABS | – acrylonitrile butadiene styrene
AL | – additive lathe
AM | – additive manufacturing
CAD | – computer aided design
CNC | – computer numerical control
DfAM | – Design for Additive Manufacturing
DOF | – degrees of freedom
FDM | – fused deposition modeling
HMI | – Human Machine Interface
PC | – polycarbonate
PCL | – polycaprolactone
PID | – Proportional-Integral-Derivative controller
PLA | – polylactic acid
PWM | – Pulse Width Modulation
SLA | – stereolithography
SLS | – selective laser sintering
STL | – STereoLithography – triangle mesh file format
VFA | – vertical fine artifacts

List of Important Symbols

A | – surface area [mm² ]
de | – Euclidean distance [mm]
E | – extrusion parameter value in G-code [mm]
ℎl | – radial layer thickness [mm]
ig | – mechanical gear ratio
I | – surface coverage intensity

J – Jacobian matrix of coordinate transformation

Kp, Ki | , Kd – PID controller parameters (proportional, integral, derivative)
l | – segment length [mm]
r | – radius or distance of a point from the rotation axis in the cylindrical coordinate system [mm]
rd | – working drum radius of the cylindrical printer [mm]
ri | – radius of the i-th cylindrical layer [mm]
s | – arc length on the cylindrical surface [mm]
Tg | – glass transition temperature of the material [°C]
Tm | – melting temperature of the material [°C]
Tn | – extruder nozzle temperature [°C]
V | – volume [mm³ ]
w | – extrusion path width [mm]
x, y, z | – Cartesian coordinates of a point [mm]
θ | – radius angle in the cylindrical coordinate system [°]

σx, σy, σz – positioning uncertainty in Cartesian axes [mm]

σr , σθ , σℎ – positioning uncertainty in cylindrical axes [mm, rad, mm]

### 1. INTRODUCTION

The wide availability and low entry barrier, contrasting with the array of possibilities offered by three-dimensional printing technology, have attracted hobbyists, engineers, and artists from all over the world. The birth, blossoming, and maturation of additive manufacturing fueled by the cooperation of people acting for the benefit of the entire community turned into an ecosystem of mutual inspiration and open knowledge sharing, where science, engineering, and art coexist and drive each other.

### 1.1. Development of FDM technology

Fused deposition modeling (FDM) is the most popular of the additive manufacturing (AM) processes. FDM technology experienced rapid development after its democratization in 2009, following the expiration of the 1988 Stratasys patent [1]. The essence of the FDM process lies in the careful, layer-by-layer deposition of plasticized thermoplastic until a new object is formed. The material is supplied by an extruder and distributed from a nozzle, whose precise positioning is ensured by a computer numerical control (CNC) machine.

In the initial phase of its development, the innovative production technology of FDM was perceived primarily as a tool supporting rapid prototyping, rather than an independent method of manufacturing goods. The decade 2010–2020 was characterized by dynamic technical progress of FDM technology and market development, with a significant part of the contributions attributed to the open source community. Currently, at the moment of technical maturity of printing machines and the advancement of production materials, the actual usefulness of FDM technology in manufacturing processes is primarily determined by the development of design methodologies dedicated to additive manufacturing (DfAM) [2].

### 1.2. Aim and scope of the thesis

The main aim of the thesis is to develop a prototype of a cylindrical 3D printer as an independent machine. Special attention is also paid to path planning algorithms, including the conditions that must be met to fully utilize the advantages of cylindrical geometry.

1.2.1. Research objectives

The work began with an analysis of technical literature regarding existing implementations of cylindrical printers, in order to identify optimal physical construction solutions. Design works and implementations focus on the construction of a dedicated cylindrical machine, in contrast to the approach used in the literature so far based on the adaptation of conventional Cartesian printers. Designing the printer from scratch allows for the optimization of the system architecture for specific requirements of cylindrical kinematics, and makes the solution independent from external manufacturers. The final goal of the work is the physical implementation of the machine 1.1 and the production of simple prints with geometry impossible to achieve on standard Cartesian printers. The implementation aims to indicate the direction of technology development and identify potential system problems in real-world conditions.

1.2.2. Scope and limitations of the thesis

Limiting the scope of the thesis aims to ensure the achievability and reproducibility of the project. The adopted limitations concern construction materials, electronic components, and the scope of functionality of the prototype. The work attempted to use available open source solutions and components widespread in RepRap-type printers or their commercial counterparts. Structural elements were designed to allow their production using a standard FDM-type 3D printer, without the need for advanced tools or equipment.

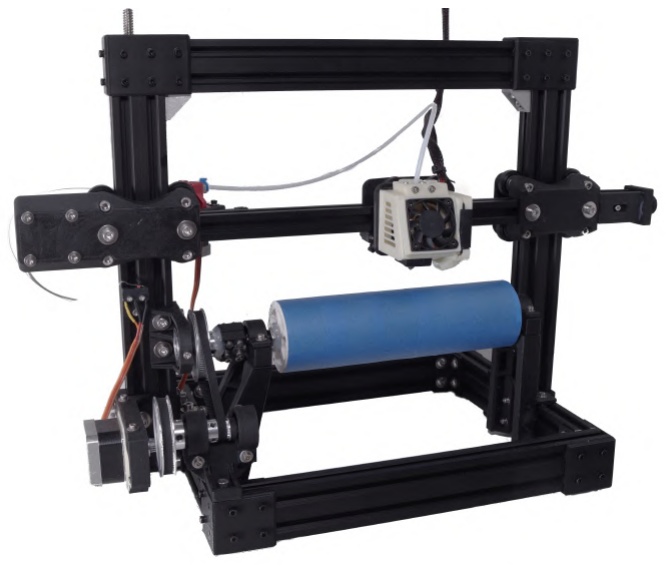
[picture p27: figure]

Figure 1.1: Photograph of the physical implementation of the cylindrical printer made as part of the project

The prototype of the created cylindrical printer 1.1 omits a number of functions that would be necessary in a fully functional machine. The omitted functions include: lack of a work surface leveling system; lack of a dedicated Human Machine Interface (HMI); lack of a closed feedback loop for controlling the angular position of the drum. Open-loop control with a stepper motor can lead to the accumulation of positioning errors in long-term processes requiring multiple revolutions of the drum or high moments of inertia of the print.

1.2.3. Thesis organization

The "Literature review" chapter is dedicated to a detailed analysis of the technical state of the mechanical structures of cylindrical printers and toolpath generation algorithms. Examples of mechanical structures on the basis of which the prototype of the physical implementation was planned, approaches to path generation, and applications of cylindrical printers are described.

The "Mathematical foundations" chapter presents the fundamental mathematical concepts on which cylindrical print path generation algorithms are based. An analysis of resolution and positioning accuracy in the cylindrical system was also performed, on the basis of which the required specifications of the cylindrical printer prototype were determined.

The "System design and architecture" chapter describes the design and implementation process of the physical prototype of the cylindrical 3D printer. It discusses the mechanical architecture of the machine, the selection of electronic components, and construction solutions ensuring the required positioning resolution. The tested rotary drive mechanical reduction systems, linear axis drive system, electronics, control system, and Marlin software adaptations are

presented.
The "Manufacturing capabilities and applications" chapter presents an analysis of design principles for additive manufacturing in the context of both Cartesian and cylindrical printers. The first part of the chapter contains a presentation of limitations and good design practices in standard FDM printing, on which the second part is based, presenting the unique geometric advantages of cylindrical printing.
The "Toolpath generation" chapter presents the methodology of trajectory planning for a cylindrical printer. It discusses path generation approaches used in the literature on the subject, along with their limitations and possibilities. Based on the concepts of the discussed path generation approaches, new solutions are proposed and their implementations are presented. Directions for further development of slicing algorithms technology for cylindrical kinematics are indicated.

### 2. LITERATURE REVIEW

### 2.1. Limitations of Traditional FDM Technology

FDM technology struggles with a number of limitations that constitute a barrier to its application in many branches of industry. Most of these barriers stem from the geometric limitations of the technology, production time, and frequently insufficient mechanical properties.

Geometric and Time Limitations

Among the most critical limitations are geometric barriers related to manufacturing structures with a non-planar orientation. As noted by Zhao and co-authors [3]: “Traditional XYZ printers are perfectly adept at planar layer slicing but encounter limits when fabricating non-horizontal structures, overhangs, and components with complex geometry [4–6], which require support structures [2], increasing both production time and material costs”. Increasing the power of actuators can certainly yield improvements in production times, but it is directly tied to an increase in costs and does not address the methodology’s problems. The aforementioned support structures are not an integral part of the process; they result from geometric limitations and the inability to print without support.

Mechanical Property Limitations

Currently used filaments, which are the primary form of delivering raw material from the extruder nozzle, are characterized by significantly lower strength and stiffness compared to ceramics or metals commonly used in industry. The range of available materials includes, among others, polymers, foams, and composites; however, regardless of the material used, the FDM process does not allow for achieving fully isotropic mechanical properties of the base material. This is due to the nature of the additive process of layer deposition and the extrusion of material strands. Interlayer adhesion remains significantly weaker than the strength in the direction parallel to the continuous lines within a single layer, which manifests as a strong anisotropy of the mechanical properties of the manufactured part.

2.1.1. Non-planar Printing

The above problems are being addressed by research into non-planar 3D printing technologies, implemented by printers with a non-Cartesian architecture or systems characterized by an increased number of degrees of freedom (DOF). These solutions allow for the elimination of support structures and enable the orientation of successive material layers in accordance with the predicted directions of mechanical stress propagation. Non-planar printing theoretically allows for achieving near-isotropic strength properties; however, optimal tool path planning and the complication of inverse kinematics, caused by the addition of further degrees of freedom of movement, remain a problem.

2.1.2. Cylindrical Printers and Their Applications

The simple kinematics of cylindrical printers, combined with the coverage of a wide range of geometries different from those possible to produce on classic FDM printers, can provide a solution to the problem that printers with an increased number of degrees of freedom are attempting to solve. The design of cylindrical printers modifies Cartesian 3D printers with an X gantry on an elevated OZ axis (Cartesian gantry Z-lift) by replacing the moving bed (linear movement in the OY axis) with a rotating drum performing rotary movement around the OX axis. This simple change opens up new possibilities for manufacturing geometries that were previously difficult or impossible to realize in conventional Cartesian systems. It becomes possible to print elements such as propellers and rotors, structures with spiral geometry (springs, screws), components of a lathe nature with consideration for internal geometry, as well as biological tubular structures, including blood vessels, without supports.
The application of cylindrical printing technology in the context of bioprinting is particularly desirable, as it can enable the creation of robust biological constructs. Reeser and co-authors state [7]: “A confounding issue in the 3D printing of biomaterials is the collapse or deformation of structures caused by the weak mechanical properties of common biomaterials. This can be particularly problematic for constructs containing voids, especially tubular biological structures. [. . . ] The lathe-printer supplies a methodology for building such structures radially outward one layer at a time, as opposed to the complex coordination required to co-print biomaterials with unique properties, different cell types, and support structures”. Coupled with the latest advancements in bioprinting, such as ultra-high-resolution printing of lines with a width of 20 μm using a mosquito proboscis [8], 3D printing technology opens up possibilities for manufacturing advanced organic structures.

### 2.2. Existing Implementations of Cylindrical Printing

Despite more than a decade passing since the proposal of the first prototypes, cylindrical printing technology remains a niche solution, not crossing the boundary of research laboratories. Research teams interested in developing this technology most often decide to adapt existing Cartesian printers. To date, no team has yet developed complete software for planning the manufacturing process tool paths.

2.2.1. Overview of the Development of Cylindrical Printer Technology

The first physical prototype of the additive lathe (AL) technology was presented by Yoav Sterman in 2011 as part of a project called “The Additive Lathe” [9]. This prototype had numerous mechanical limitations, the most significant of which was the inability to adjust the distance between the cylinder and the print head. This approach made it impossible to apply successive layers of material. From a topological point of view, it was merely a two-dimensional machine operating on a cylindrical surface. In 2013, Kenich and colleagues developed the first prototype capable of movement in the Z direction [10]. This system, inspired by the open-source RepRap Mendel printer, was the first functional AL printer.

The latest achievements in the field of cylindrical printing were presented by Zhao and co-authors [3], who developed a cost-effective implementation of a rotary FDM printer based on the modification of the popular Prusa i3 MK3s printer. The task of the control system was performed by the Duet 2 WIFI motherboard and RepRap firmware version 3.1.1.

The process planning methodology developed by Zhao and co-authors is based on surface mapping and includes a twelve-step cylindrical slicing algorithm. The process begins by importing a 3D model in STL format, followed by the calculation of the central axis of the model and ensuring its coaxiality with the center of the rotary build platform. The system generates concentric cylindrical slicing surfaces in the radial direction, which intersect with the 3D model to extract the contours of each curved layer. Contour points in Cartesian coordinates (xc, yc, zc) are then mapped to points (rc, ℎc, θc) in cylindrical coordinates on the cylindrical surface. The final stage is generating control code compliant with the G-code format.

2.2.2. Contemporary Implementation in the Field of Bioprinting

In the field of bioprinting, where the weak mechanical properties of common biomaterials pose a challenge, cylindrical printing enables the construction of tubular structures radially outward layer by layer, eliminating the problem of the structure collapsing under its own weight. Sichuan Revotek Co. Ltd. announced in 2016 the successful implantation of bioprinted blood vessels into thirty Rhesus monkeys, although these results were not published in a peer-reviewed journal [11; 12].
The technology has also demonstrated utility in manufacturing stents from bioresorbable polymers. Guerra and co-authors conducted systematic studies on the influence of printing parameters (temperature, speed, material flow rate) on the physical properties of PCL stents [13– 15]. The research culminated in the successful application of pneumatic composite actuators in the field of soft robotics.

### 2.3. Analysis of the Research Gap

The broader application of AL technology remains hindered by the lack of available software for generating tool paths that includes the capabilities of modern slicers. Various research teams have developed proprietary workarounds for this problem: Kenich and colleagues applied the Slic3r platform in an unconventional way, modeling parts as flat, which limited the complexity of the geometries that could be manufactured. Coulter and co-authors implemented the most advanced software solution, utilizing the Grasshopper3D plugin for the Rhino software to create reconstructions of scanned doubly-curved surfaces and generate tool paths along these curved surfaces [16; 17]. Solutions used so far have strong geometric limitations or do not exploit the advantages of cylindrical printer geometry.
Cylindrical space is characterized by variable angular resolution as a function of the radius, which makes the use of mechanical reduction or microstepping of stepper motors necessary to maintain adequate resolution. Implementations realized to date rely exclusively on systems with microstepping of stepper motors, which can lead to a decrease in the holding torque of stepper motors, and consequently cause skipped steps or the emergence of vertical fine artifacts (VFA). The use of a dedicated mechanical reduction in the drum drive system can improve positioning resolution without excessive microstepping operation.

### 3. MATHEMATICAL FOUNDATIONS

This chapter deals with issues related to coordinate system transformations used in toolpath generation algorithms, as well as calculations of required resolutions, upon which the requirements of the mechanical design of the project were based.

### 3.1. Manufacturing in a Cylindrical Coordinate System

Fully utilizing the potential of the cylindrical printer geometry, both in terms of the mechanical properties of the manufactured components and the visual quality of their execution, requires the direct integration of the cylindrical coordinate system into the design process. Regardless of the number of degrees of freedom or the kinematic configuration of the machine using FDM technology, workpieces are manufactured in the process of sequential deposition of successive material layers. The orientation of the layer planes relative to the geometry of the manufactured element has a significant impact on the distribution of mechanical stresses, the quality of the surface finish, and the accuracy of curvature mapping. Cylindrical surfaces become the most natural and effectively mapped type of geometry, while flat surfaces, such as the walls of a cuboid or a cube, in cylindrical geometry are subject to the formation of characteristic stair-stepping effect artifacts.

3.1.1. Methods of Space Description

Traditional computer-aided design (CAD) programs define the workspace in a Cartesian coordinate system, utilizing three mutually perpendicular axes to parameterize three-dimensional models. From the designer’s point of view, the geometry of the object in real space is significant; cylindrical and Cartesian coordinate systems describe the same space in two different ways, so the use of a cylindrical or Cartesian system to describe an object does not matter. On the other hand, from a manufacturing point of view in FDM technology, three-dimensional space is constructed from discrete sections of two-dimensional space. The realization of three-dimensional space in the Cartesian system is directly a subset of Euclidean space with discretization along the Z axis. However, describing real space using the layers of a cylindrical system requires the use of continuous cylindrical planes representing non-Euclidean two-dimensional space.

3.1.2. Coordinate System Transformations

Because the design of elements typically takes place in CAD programs, which use the Cartesian coordinate system as the basic workspace, the AM process requires the application of appropriate transformations to the cylindrical coordinate system. The analytical equations of the transformation allow for the transition between the cylindrical and Cartesian systems, however, they can also be used as a tool to transform the geometry of the object itself.

Cartesian Coordinate System

The Cartesian coordinate system is defined by three mutually perpendicular axes (OX, OY, OZ). The position of any point P in space is unambiguously determined by the triplet of coordinates (x, y, z), where:

- x ∈ R – the coordinate along the OX axis, representing the displacement in the horizontal direction,
- y ∈ R – the coordinate along the OY axis, representing the displacement in the perpendicular direction to the OX axis in the horizontal plane,
- z ∈ R – the coordinate along the OZ axis, representing the displacement in the vertical direction.

The position vector of point P in the Cartesian system can be expressed as:

r®cart = x e®x + y e®y + z e®z =

x

y

z

, | (3.1)

where e®x, e®y, e®z denote the versors (unit vectors) of the respective axes.

Cylindrical Coordinate System

The cylindrical coordinate system is an alternative system of parameterizing three-dimensional space, particularly useful in describing axisymmetric geometries and rotational motion. In this system, the position of point P is determined by the coordinates (r, θ, ℎ), where:

- r ∈ [0, +∞) – radius, indicating the distance of the point from the OZ axis (the axis of rotation),
- θ ∈ [0, 2π) – azimuthal angle, determining the angular position relative to a chosen reference plane, by default the X Z plane,
- ℎ ∈ R – height along the cylinder axis, corresponding to the z coordinate in the Cartesian

system.

| The cylindrical system is a natural choice for machines with rotational kinematics, such as
AL, because it directly corresponds to the degrees of freedom of the mechanical system: rotation around the axis, radial displacement, and longitudinal displacement.

Transformation Equations

The transformation between the Cartesian and cylindrical systems is reversible and described by the following analytical relationships. The conversion from the cylindrical system (r, θ, ℎ) to the Cartesian system (x, y, z) is given by the formulas:

x = r cos(θ)

y = r sin(θ)

z = ℎ

, | (3.2)

The geometric interpretation of equations (3.2) involves projecting a point defined by radius r and angle θ onto the XY plane while preserving the height coordinate z = ℎ.
The inverse transformation, from the Cartesian system (x, y, z) to the cylindrical system (r, θ, ℎ), is expressed as:

r =

√︁
x

2 + y

2

θ = arctan 2(y, x)

ℎ = z

, | (3.3)

where the function arctan 2(y, x) returns the angle in the full range [0, 2π) or (−π, π], depending on the implementation, taking into account the signs of both arguments to unambiguously determine the quadrant. The height coordinate ℎ remains unchanged in both systems, therefore, the OZ axis in the Cartesian system coincides with the cylinder axis in the cylindrical system.

The presented transformation equations describe a global coordinate conversion; however, fully understanding the geometric properties of this transformation also requires an analysis of its local differential characteristics, which allow determining the propagation of positioning errors, metric distortions, and the dependence of spatial resolution.

Transformation Jacobian Matrix

The transformation Jacobian matrix is obtained by calculating the partial derivatives of the Cartesian coordinates (x, y, z) with respect to the cylindrical coordinates (r, θ, ℎ). Differentiating equations (3.2), we obtain the Jacobian matrix of the transformation from the cylindrical to the Cartesian

system:

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
cos(θ) −r sin(θ) 0
sin(θ) | r cos(θ) | 0
0 | 0 | 1
. | (3.4)

The determinant of the Jacobian matrix is expressed as:

|J| = r. | (3.5)
The positive value of the determinant |J| = r, r | > 0 confirms that the transformation
preserves spatial orientation, and determines the local volume scaling factor during the transformation: the volume element dVcart = dx dy dz in the Cartesian system corresponds to the element dVcyl = r dr dθ dℎ in the cylindrical system.

The linear dependence of the Jacobian determinant on the radius r is visible, thus for a constant angle increment Δθ the arc length that a point travels on the cylinder surface increases proportionally to the radius:

Δs = r · Δθ. | (3.6)

In order to maintain a constant linear print resolution at different radii, it is necessary to apply a variable angular resolution, or a sufficiently high angular resolution to avoid discretization errors throughout the working volume. This property has direct consequences for both the mechanical design of the additive lathe-printer and the software realization of positioning.

3.1.3. Cylindrical Toolpath Planning in AM

The transformation of three-dimensional object models into motion instructions for the print head is typically performed using specialized software called a slicer. In the traditional approach to additive manufacturing, used in Cartesian printers, the method of generating toolpaths involves intersecting the 3D model mesh with a series of planes parallel to the build platform. Successive layers are separated from each other by a layer height distance ℎl or Δz. For the most commonly used nozzle with an exit orifice diameter of 0.4 mm, a typical layer height falls in the range of 0.12 mm to 0.32 mm. Based on the flat cross-sections created in this way, the slicer algorithms calculate the toolpaths and the material feed rate.

The difference in cutting planes between the Cartesian and cylindrical systems means that the paths generated for a Cartesian printer cannot be directly used for an additive lathe-printer. An analogous solution would require writing a slicing program from scratch. Considering the complexity of modern slicers, writing a new slicer is a task too complex for a single research team. The fifth chapter describes alternative methods of generating toolpaths described in the literature, along with a proposal for a new solution and direction of technology development.
In the cylindrical slicing process, concentric cylindrical surfaces, used to cut the 3D model, are defined by the equation:

(x − xc)

2 + (y − yc)

2 = r

2
i
, | (3.7)

where i ≥ 1 denotes the number of the cutting surface and the radii of successive cylindrical surfaces satisfy the condition rmax ≥ ri ≥ rmin. The minimum radius value rmin corresponds to the internal surface of the manufactured element, while rmax defines its external surface. The layer height in cylindrical printing is defined as the difference between the radii of two adjacent cutting surfaces:

ℎl = ri+1 − ri

for i ≥ 1. | (3.8)

### 3.2. Technical Challenges of Cylindrical Printing

The angular resolution of the realized trajectory changes as a function of the radius 3.6. Maintaining adequate print quality with an increasing diameter of the manufactured element requires applying sufficient angular resolution. The determination of the appropriate resolution was carried out based on an analysis of the impact of mechanical reduction and microstepping on the minimum step length and error accumulation.

3.2.1. Resolution and Position Accuracy Analysis

The linear resolution in the Cartesian system for the OX and OY axes, driven by timing belts, is expressed by the formula:

Δx = Δy =

pb

ns · m

, | (3.9)
where pb denotes the pitch of the timing belt (the distance between teeth), ns | is the number of
motor steps per revolution (standard 200 for NEMA 17 motors), and m represents the number of microsteps. Analogously, for the OZ axis driven by a lead screw:

Δz =

ps

ns · m

, | (3.10)

where ps denotes the lead screw pitch.
For a typical mechanical configuration, the linear resolution of individual Cartesian axes is expressed as follows: the OY axis driven by a GT2 timing belt (pitch pb = 2 mm) with a 16-tooth pulley achieves a resolution:

Δy =

pb · Nt

ns · m

=

2 × 16
200 × 16
= 0.01 mm, | (3.11)

where Nt = 16 denotes the number of teeth on the drive pulley. For the OZ axis using a T8 lead screw with a pitch of ps = 8 mm, the resolution is:

Δz =

ps

ns · m

=

8
200 × 16
= 0.0025 mm. | (3.12)

The resolution of the OZ axis (0.0025 mm) is four times higher than the OY axis (0.01 mm), for a system consisting of the most common combination of components. The discrepancy can be explained based on the accuracy requirements for individual directions. The layer height in the FDM process is usually in the range of 0.08–0.3 mm, while the positioning accuracy in the horizontal plane must ensure precise reproduction of the contour geometry with a line width of about 0.4 mm for a standard nozzle. Normalizing the resolution against the required dimensions, we obtain: for the OZ axis a ratio Δz/ℎl ≈ 0.0025/0.08 ≈ 3.1%, and for the OY axis a ratio Δy/(wl/2) ≈ 0.01/0.2 = 5% (where wl ≈ 0.4 mm denotes the line width).
In the cylindrical system, the angular resolution of the rotary axis with a mechanical transmission is expressed as:

Δθ =

2π

ns · m · ig

, | (3.13)

where ig denotes the gear ratio of the reducer (for ig = 1 the transmission is absent). The arc resolution at radius r is then:

Δs(r) = r · Δθ = r ·

2π

ns · m · ig

= k · r, | (3.14)

where the proportionality coefficient k =

2π

ns ·m·ig

is constant for a given hardware configuration. The total gear ratio of the rotary system is defined as the product of microstepping and the mechanical gear ratio: itotal = m · ig. Table 3.1 presents the values of arc resolution Δs for different total gear ratios and selected values of radius r, assuming a standard NEMA 17 motor (ns = 200).

Table 3.1: Arc resolution Δs [mm] as a function of radius r and the total gear ratio of the rotary system for a NEMA 17 motor

r [mm]

Total gear ratio itotal = m · ig

| 1 | 16 | 32 | 64
10 | 0.0196 | 0.00123 | 0.000614 | 0.000307
50 | 0.0982 | 0.00614 | 0.00307 | 0.00153
100 | 0.1963 | 0.0123 | 0.00614 | 0.00307
200 | 0.3927 | 0.0245 | 0.0123 | 0.00614

The analysis of Table 3.1 shows that a standard NEMA17 stepper motor (without a gear ratio itotal = 1) achieves a minimum arc resolution at radius r = 200 mm of as much as 0.4 mm. The value of 0.4 mm is 40 times higher than the resolution of the OX axis, which would cause significant measurement inaccuracies and uneven material distribution. A total gear ratio of itotal = 16 reduces the arc resolution sixteenfold, which for r = 200 mm gives a value of 0.0245 mm, already close to the typical resolution of Cartesian printers, but still insufficient. If we take the resolution on the OX axis, amounting to 0.01 mm, as the target resolution metric, the preferred combination requires a total reduction of ig ≈ 32.
Achieving the required total gear ratio is possible through various combinations of microstepping and mechanical reduction. For example, a total gear ratio of itotal = 16 can be achieved using 1/16 microstepping without a gear ratio (m = 16, ig = 1), or 1/8 microstepping with a 2:1 gear ratio (m = 8, ig = 2). The choice of a specific combination depends on a compromise between the torque of the stepper motor (which decreases as microstepping increases), smoothness of movement (which increases with higher microstepping), and the complexity of the mechanical structure (which grows with an increase in the gear ratio ig). Because the moment of inertia of the working drum, combined with the impact of the mass of the created print, can reach high values of torque acting on the stepper motor, there is a risk of exceeding the motor’s holding torque with a high degree of microstepping. Mechanical reduction provides both an improvement in resolution and a mechanical advantage reducing the impact of the drum’s moment of inertia on the stepper motor; thus, increasing the value of mechanical reduction allows the use of a greater degree of microstepping.

Error Propagation Analysis

The analysis of positioning error propagation between coordinate systems requires taking into account the differential dependencies of the transformation. The position uncertainty in the Cartesian system is expressed as:

σpos,cart =

√︃

σ

2
x + σ

2
y + σ

2

z

, | (3.15)

while in the cylindrical system the corresponding expression takes the form:

σpos,cyl =

√︃

σ

2
r + (r · σθ )

2 + σ

2
ℎ
. | (3.16)

The component (r·σθ )

2
reveals the dependence of position uncertainty on the radius. The impact of the angular error σθ on the total positioning uncertainty is not linear.
The error propagation from the cylindrical to the Cartesian system results directly from the Jacobian matrix of transformation (3.4). Differentiating the transformation equations (3.2) and applying the law of propagation of uncertainty, we obtain the error components in the Cartesian

system:

σ

2
x =
∂x

∂r 2

σ

2
r +
∂x

∂θ 2

σ

2

θ = cos²
(θ) σ

2
r + r

2

sin²
(θ) σ

2
θ
, | (3.17)

σ

2
y =
∂y

∂r 2

σ

2
r +
∂y

∂θ 2

σ

2

θ = sin²
(θ) σ

2
r + r

2

cos²
(θ) σ

2
θ
, | (3.18)

σ

2
z = σ

2
ℎ
. | (3.19)

Summing components (3.17) and (3.18), taking into account the trigonometric identity sin²
(θ) + cos²
(θ) = 1, we get:

σ

2
x + σ

2
y = σ

2

r

(cos²

(θ) + sin²
(θ)) + r

2σ

2
θ

(sin²

(θ) + cos²
(θ)) = σ

2
r + r

2σ

2
θ
| | , | (3.20)

which confirms the independence of the total position error from the angle θ and the linear dependence of the angular component on the radius r.
Assuming that positioning errors are dominated by the discrete resolution of the mechan-
ical system, the uncertainties can be approximated as: σr | ≈ Δr, σθ | ≈ Δθ, σℎ | ≈ Δz. From
equation (3.20) it follows that the angular component of the position error is r · σθ = r · Δθ, making it analogous to the arc resolution Δs(r) from Table 3.1.
The relative contribution of the angular component to the total positioning error can be determined by calculating the percentage share of (r · σθ )

2
in the total squared error. Assuming typical error values for the radial axis and height comparable to the Cartesian axes (σr ≈ 0.01 mm, σℎ ≈ 0.0025 mm), Table 3.2 presents the total positioning error and the percentage share of the angular component for selected configurations.
Table 3.2 presents the overall significance of the angular error in the cylindrical system. For large working radii (r = 200 mm) with insufficient gear ratio (itotal = 16), the angular component accounts for as much as 85% of the total squared error affecting positioning precision. Increasing

Table 3.2: Total positioning error σpos,cyl and the percentage share of the angular component for σr =

0.01 mm, σℎ = 0.0025 mm

r [mm] | itotal | r · σθ [mm] | σpos,cyl [mm] | Angular share [%]
100 | 16 | 0.0123 | 0.0161 | 58.7
100 | 32 | 0.00614 | 0.0120 | 26.2
200 | 16 | 0.0245 | 0.0266 | 85.0
200 | 32 | 0.0123 | 0.0161 | 58.7
200 | 64 | 0.00614 | 0.0120 | 26.2

the gear ratio to itotal = 32, a value deemed the target based on the analysis of Table 3.1, reduces this share to 59% – which means that the error share dominates and exceeds the combined error of the OX and OZ axes. A reduction level with itotal = 64 lowers the error share to 26%, making the errors of all axes comparable. Therefore, to preserve balanced spatial precision at large working radii (r ≥ 200 mm), a total gear ratio of itotal ≥ 64 is required.

Resolution Analysis Conclusions

Microstepping of stepper motors provides smoother movement, noise reduction, and better surface finish quality. However, this method is characterized by a decrease in holding torque as the microstepping degree increases, which limits the ability to manufacture objects with high inertia and forces a reduction in printing speed by reducing acceleration and the instantaneous acceleration change value (jerk). An alternative solution is to apply mechanical reduction in the rotary system, which allows maintaining full torque while simultaneously increasing angular resolution. A practical solution involves combining both methods and adapting the required resolution to the machine’s dimensional assumptions. Based on the calculations of the impact of error components, it was decided that the target total gear ratio is itotal ≥ 64.

### 4. SYSTEM DESIGN AND ARCHITECTURE

The overarching goal of the adopted design strategy was to maximize accessibility and reproducibility of the project. Efforts were made to utilize open source solutions prevalent in RepRap 3D printers and their commercial equivalents. The applied components, both mechanical and electronic, are widely used in the construction of 3D printers and CNC machines, ensuring high availability and simplifying the adaptation process of existing solutions. The total cost of mechanical and electronic materials amounted to approximately 800 PLN.


Figure 4.1: Render of the created CAD printer project

### 4.1. Mechanical Design

The mechanical structure design of the AL was executed considering the assumptions of open source solution compatibility and budget constraints. The main structural element comprises aluminum profiles. The remaining parts, including connecting elements, brackets, and gears, were manufactured using 3D printing. The implementation utilized a ready-made MK8 hotend and a Bowden extruder attachment for a stepper motor. The visualization of the printer’s CAD project, created for the purpose of the project, is presented in figure 4.1.

4.1.1. Structural Frame

The design utilizes aluminum profiles with cross-sections of 20 × 20 mm and 20 × 40 mm, which allow for building a rigid structure and serve as linear guides for roller bearings. The base frame and the vertical gantry were made of profiles with a 20 × 40 mm cross-section, while the sliding system carrying the printhead was constructed from a lighter 20 × 20 mm profile. Inside the aluminum profile channels, a GT2 timing belt was routed to execute the linear movement of the printhead, driven by a stepper motor.

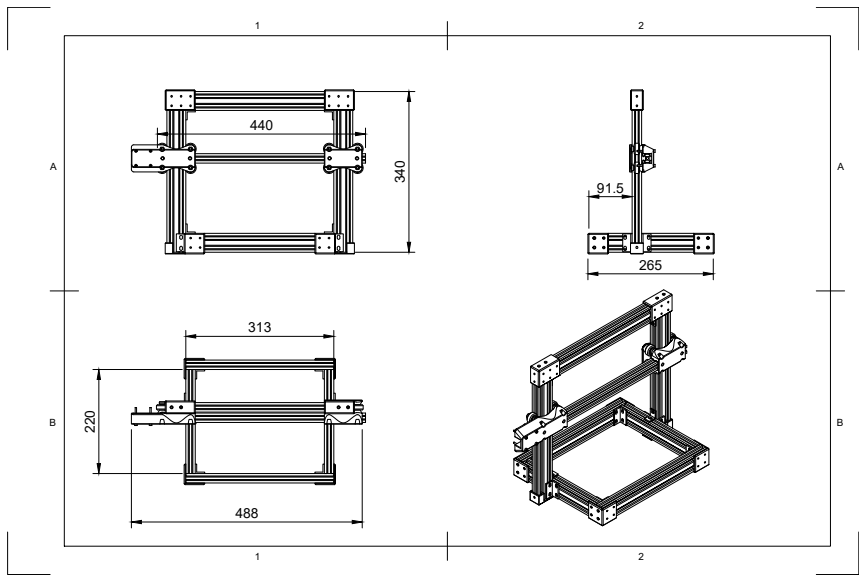
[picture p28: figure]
265 ³⁴⁰

Figure 4.2: Structural frame schematic

Figure 4.2 presents a schematic of the structural frame with dimensions given in millimeters. Segment A1 contains the front view; segment B1 contains the top view; segment A1 contains the side view; segment B2 contains the isometric view.

The aluminum profile connectors were designed based on the cross-sectional profile of the aluminum profile. The connectors feature rails that allow them to slide into the profile ends, and the connections were made using T-slot nuts.

4.1.2. Selection of Materials for 3D Printing of Structural Components

The selection of appropriate polymers for 3D printed components considered mechanical and thermal requirements. Parts directly adjacent to elements generating significant amounts of heat, i.e., stepper motors and the extruder, were made of PC/ABS, a polymer blend of polycarbonate (PC) and acrylonitrile butadiene styrene (ABS). The PC material is characterized by a high yield temperature (glass transition temperature Tg ≈ 147°C) and an exceptionally high melting point (Tm ≈ 267°C), which means it is resistant to thermal deformation in the vicinity of the extruder heater and in direct contact with stepper motors. Stepper motors can reach casing temperatures ranging from 60°C to 80°C under prolonged operation conditions. As an additional heat dissipation mechanism, metal frame elements were utilized, functioning as a heatsink in this case, dissipating heat generated by the motor windings over a large surface area.

Pure PC exhibits a very high linear shrinkage of 1.0 to 2.5%, which entails an extremely high risk of deformation and detachment from the buildplate during the printing process. For this reason, manufacturing components from pure PC requires the use of an enclosed printing chamber with controlled ambient temperature. Since most consumer machines lack ambient printing temperature control, a filament with an ABS admixture was used. Adding the ABS admixture (whose linear shrinkage is 0.8 to 1.5%) to the PC/ABS composite significantly lowers the total shrinkage of the blend and improves adhesion to the build surface, allowing for the production of parts on printers lacking a heated chamber. The resulting filament still has high shrinkage, so to further minimize thermal deformations, the components were designed with as flat a base geometry as possible and with maximum contact area with the buildplate. The printing process was executed using elevated buildplate temperatures (Tb > 100°C, recommended 110 to 120°C) as well as a brim feature with a width of 15 to 20 mm, which increases the adhesion area of the bottom layer and counteracts the warping of corners, and a draft-shield feature that reduces the risk of creating convection currents cooling the produced part. Such a print process configuration enables reliable manufacturing of PC/ABS elements on commonly available consumer printers like the Ender 3 or Prusa i3.
The remaining structural components, characterized by moderate mechanical requirements and not subject to long-term exposure to elevated temperatures, were made of polylactic acid (PLA). The PLA material stands out for its exceptional ease of processing in FDM technology, exhibits minimal linear shrinkage (around 0.3 to 0.5%), prints at low extrusion temperatures (190 to 220°C), and does not require a heated buildplate. A limitation of PLA material is its low glass transition temperature (Tg ≈ 60°C), above which it loses rigidity and experiences a drastic deterioration of mechanical properties (loses load-bearing capacity), which disqualifies its use in elements directly adjacent to heat sources.

### 4.2. Kinematics

The kinematic system of the AL is based on the design of a traditional Cartesian system used in FDM printers, along with cylindrical kinematics, in which one of the linear axes is replaced by a rotary axis. The transformation of the OY axis, which traditionally executes linear movement in the transverse direction, into a rotary axis enables continuous rotation of the cylindrical build drum around the OX axis. The remaining two axes maintain linear motion, providing full freedom of nozzle positioning in the device’s workspace.
The execution of linear movements of the OX and OZ axes is based on proven solutions commonly used in RepRap printer designs. The OZ axis utilizes a gantry system, along which a beam supporting the printhead moves vertically. The aluminum profiles of the gantry serve as linear guides, and the drive is achieved using a TR8×8 lead screw connected to a stepper motor via a flexible coupling.
The X axis is driven by a GT2 timing belt, tensioned between a driving pulley mounted on the stepper motor shaft and an idler pulley with a tensioner assembly. The printhead carriage moves along the beam and, similar to the gantry axis, utilizes rollers with 608ZZ bearings.
4.2.1. Rotary Axis Drive

The design of the OY rotary axis drive system requires the ability to mount interchangeable build drums of various diameters, and a mechanical reduction itotal ≥ 64, essential for achieving sufficient angular positioning resolution. Minimizing mechanical backlash in the drive assembly is critical. The presence of backlash leads to a loss of positioning accuracy and the formation of surface artifacts during frequent changes in the drum rotation direction. In order to preserve maximum holding torque, efforts were made to minimize the system’s reliance on stepper motor microstepping.
During the structural design process, efforts were made to achieve a solution with the highest possible mechanical reduction; ultimately, a total mechanical reduction of 16:1 was accomplished, which combined with 8-fold microstepping of TMC2208 drivers provides the required resolution. During holding torque tests, it was found that the degree of mechanical reduction appropriately decreases the motor load; it was able to perform stable operation also in 16-fold microstepping mode, which provided quieter system operation. The final design features a 256-fold reduction itotal, meaning a resolution of 51 200 steps per full revolution of the drum.

Comparative Analysis of Reduction Mechanisms

To meet the requirements of the build drum drive system, in the initial project phase, the necessity to minimize the number of mechanical transitions in the kinematic chain was identified. Each connection between gears or other moving elements introduces additional mechanical backlash accumulating throughout the system. Theoretically, it was possible to achieve the required angular resolution through various combinations of mechanical reduction and motor microstepping degrees, but mechanical reduction was the priority.

Achieving high mechanical gear ratios in single-stage gearboxes requires a significant difference in gear diameters (the ratio of the number of teeth on the driven gear to the driving gear), and due to the limited dimensional precision of FDM printers, which allow reliable manufacturing of gears with a module no larger than approximately 0.75 mm, a substantial increase in gear radius to obtain a sufficient number of teeth would be necessary; this would lead to a bulky solution, preventing a compact design. During the mechanical design planning phase, solutions with significant mechanical reduction were tested; however, as the physical implementation results demonstrated, a large reduction is not necessary, and a solution featuring an 8-fold mechanical reduction paired with 8-fold microstepping operation meets the resolution requirements.

Planetary Gearbox

The first promising candidate considered as a potential reduction mechanism was a planetary gearbox. Planetary gearboxes consist of a central sun gear, a set of planetary gears, and an outer ring gear. All planetary gearbox components are theoretically possible to manufacture using 3D printing technology, and this mechanism offers high gear ratios in a compact form factor. Planetary gearboxes utilize multiple points of contact between gears, which enables the transfer of heavier loads compared to traditional spur gears. The existence of multiple reduction stages introduces the potential for substantial mechanical backlash stemming from the accumulation of clearances in individual gear meshes, which may cause issues taking print inaccuracies into account. Initial experimental tests conducted during the project planning phase using a publicly available 37:1 ratio planetary gearbox model [18] showed that this system was characterized by angular backlashes far exceeding acceptable limits for use in the precise positioning of the printer’s rotary axis.

Worm Drive

Another analyzed solution was a worm drive, characterized by its ability to achieve high gear ratio values. A 42:1 ratio worm drive was designed and tested, with the following parameters: module m = 1,25 mm, pressure angle PA = 14,5°, number of teeth z = 42, and helix angle H A = 2,2°.

To eliminate mechanical backlash, a backlash compensation mechanism via spring tension was designed, conceptually based on a publicly available project [19]. The mechanism relies on mounting the worm gear in a movable rail, pressed against the gear wheel by a set of springs. The implementation of the described solution did not yield expected results and was ultimately deemed unsuccessful in the context of the project’s requirements. The spring tension caused excessive motion resistance in the transmission. Additionally, the use of an Oldham coupling

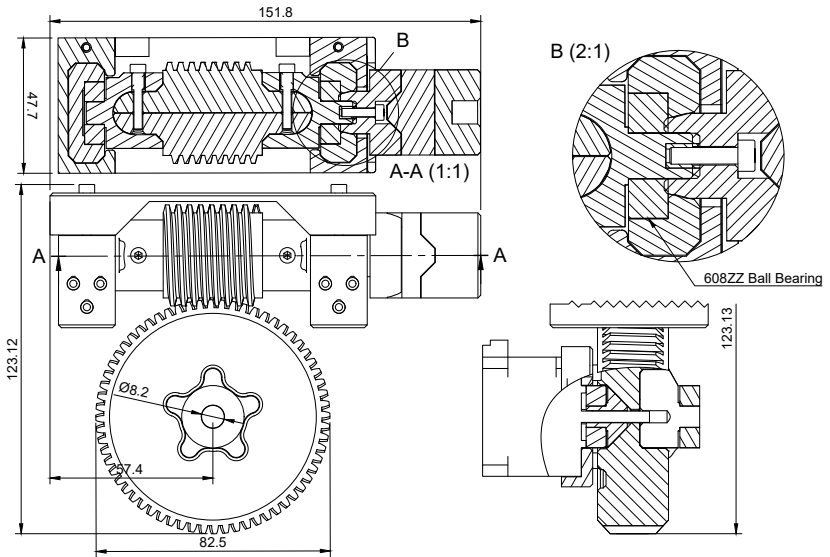
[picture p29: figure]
608ZZ Ball Bearing

Figure 4.3: Schematic of the manufactured worm drive with backlash compensation

manufactured with FDM technology reintroduced mechanical backlash to the kinematic system, negating the benefits resulting from the elimination of backlash within the worm gear mesh itself.

Two-Stage Belt Drive

The final solution applied in the AL prototype is a two-stage belt drive utilizing GT2 timing belts and pulleys with 20 and 80 teeth. The system consists of two sequentially connected reduction stages, each executing a 1:4 gear ratio, giving a combined mechanical gear ratio of 1:16. The use of 608ZZ ball bearings to support all intermediate shafts and the drum driving shaft ensures smooth rotary motion characterized by low frictional resistance. The low motor load allowed the use of 16-fold microstepping and the StealthChop operating mode of the TMC2208 drivers, which carries out active virtual smoothing of the current curve. A schematic of the belt drive is presented in figure 4.4.

The tension adjustment of the driving belts consists of shifting the drive shaft along the aluminum profile. The position of the stepper motor driving the first reduction stage and the position of the build drum drive can be adjusted individually, which allows controlling the tension degree of individual belt segments.

4.2.2. Printhead Design

In classical Cartesian printers, the nozzle position in the build plane is unambiguously defined by the coordinate system; in the AL configuration, the nozzle must be in the same plane as the rotation axis of the build drum. Otherwise, the concentricity of the print trajectory will not be preserved, and the nozzle’s distance from the working surface will be variable during drum rotation. Therefore, equipping the printhead with a mechanism enabling nozzle position adjustment along the OY axis direction is necessary. The printhead design is shown in figure 4.6.

The printhead was equipped with a fan cooling the hotend heatbreak and a part cooling fan. The purpose of the heatbreak heatsink is to prevent heat propagation up the filament feeding channel. Uncontrolled heating of the upper channel section leads to premature plasticization of

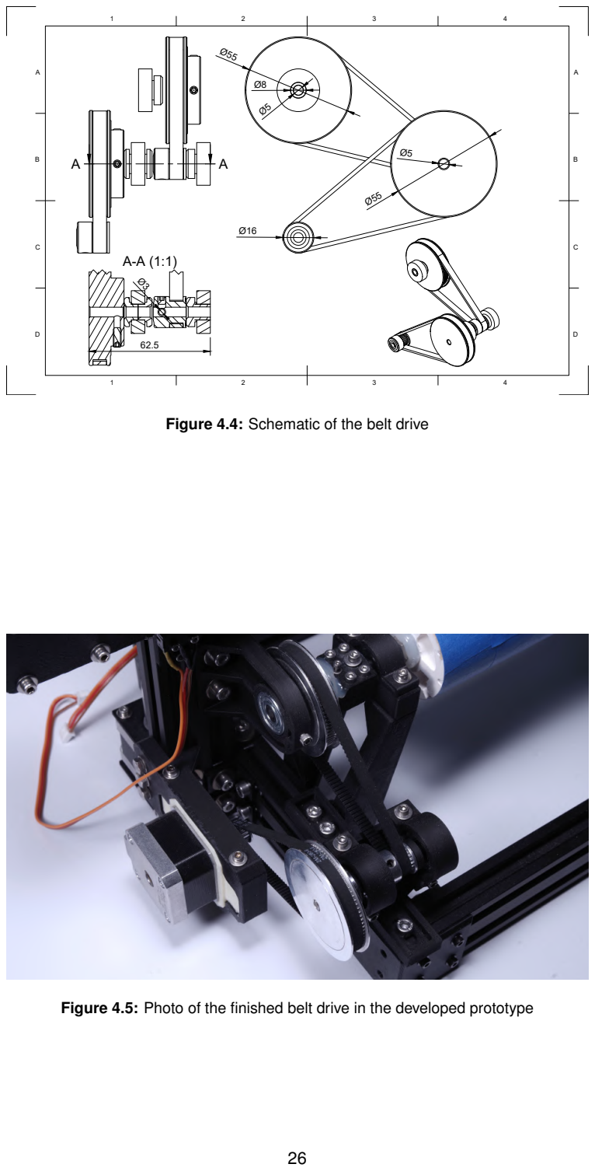
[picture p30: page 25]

Figure 4.4: Schematic of the belt drive

Figure 4.5: Photo of the finished belt drive in the developed prototype

1

A

2 | 3 | 4 | 5 | 6 | 7 | 8
1 | 2 | 3 | 4 | 5 | 6 | 7 | 8

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
Dysza MK6

Blok grzewczy

Radiator przerwy
grzewczej

1:2 ⁷⁰.61

57.44

58.35

Figure 4.6: Printhead schematic

the filament outside the melt zone, which can result in the feeding channel clogging. The part cooling fan provides cooling to the extruded material immediately after its deposition on the build surface. The air duct directs the airflow directly onto the area just below the nozzle, where the solidification of the extruded material occurs.

### 4.3. Electronics and Control System

The central control unit functions are performed by the BTT SKR V1.4 Turbo board, featuring a 32-bit ARM Cortex-M3 microcontroller (LPC1769, 120 MHz clock speed) and native Marlin firmware support. The 32-bit architecture and fast processor clock enable more accurate interpolation of cylindrical coordinates at high print speeds or high point densities.

The control of the NEMA 17 stepper motors is carried out by TMC2208 drivers, communicating with the motherboard via the UART interface. The printhead heating system consists of a 40 W heater cartridge. Temperature measurement is performed by an NTC 100k resistance thermistor. The detection of end positions for the OX and OZ axes is handled by mechanical limit switches mounted at points corresponding to each axis’s home position, utilized during the homing procedure, which is invoked during printer initialization.

4.3.1. Electrical Wiring Configuration

Four TMC2208 drivers populated in the X, Y, ZA, and E0 sockets were utilized in the printer prototype. In the default configuration, the drivers operate in legacy mode, where the microstepping level is set via hardware pins MS1, MS2, and MS3. To activate UART communication enabling software control of driver operating parameters, the factory jumpers shorting pins MS1, MS2, and RST/SLP must be removed, and then a jumper placed on pin MS3, setting it to a high state (logic 1). The UART setup in TMC2208 drivers allows for bidirectional data exchange with the integrated circuits, including setting the reference current, selecting the operating mode, and conducting a diagnostic readout of the drivers’ condition.

Electrical connections between the control board and the printer’s actuation components are presented in figure 4.7

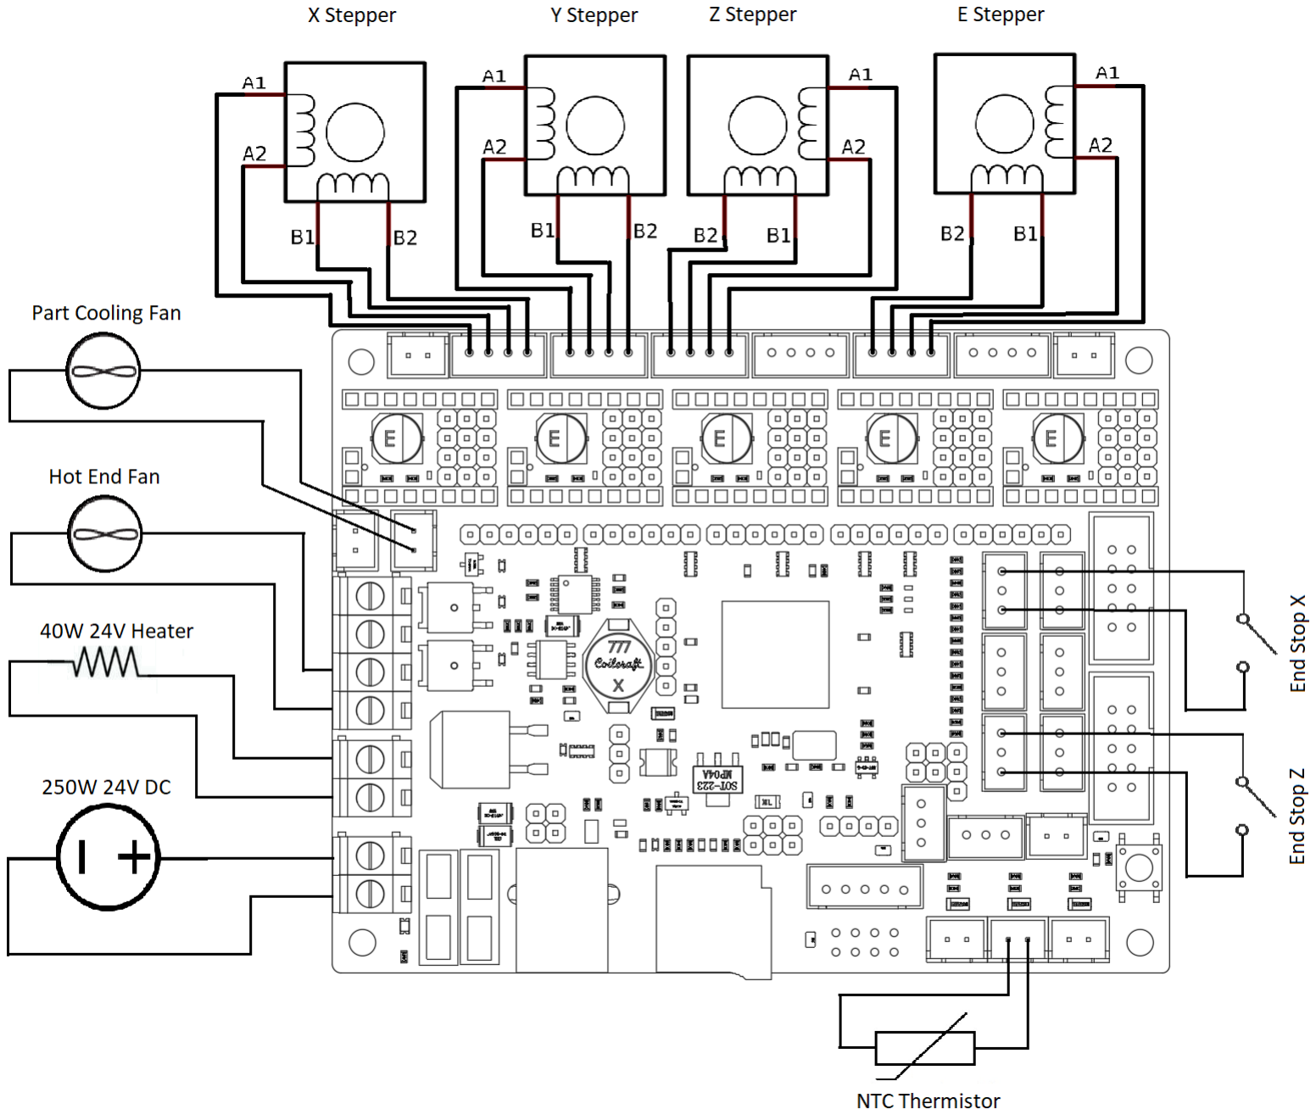
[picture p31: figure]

Figure 4.7: Printhead schematic

The extruder heater cartridge is connected to a PWM-controlled output labeled HE0, with the NTC 100k thermistor wired to the TH0 analog input. The OX and OZ axes’ limit switches are hooked up to the respective X-STOP and Z-STOP inputs. The system’s power is supplied by an external 24 V DC, 250W switching power supply. Temperature regulation is handled by a PID controller built into the Marlin firmware, which, based on temperature readings from the thermistor, modulates the power delivered to the heater by controlling the duty cycle of a PWM signal.

The BTT SKR V1.4 Turbo board features only one dedicated controllable output for a fan, which is used by the part cooling fan, labeled FAN0. The lack of a second dedicated output for the heatbreak heatsink cooling fan was resolved by connecting this fan to the HE1 port, typically intended to power a second extruder heater in setups with two independent extruders.

### 4.4. Marlin Firmware Implementation

The implementation of cylindrical kinematics in the AL prototype required substantial modifications to the control firmware configuration compared to a standard Cartesian printer setup. Marlin firmware 2.1.2.5 [20], an open source solution offering native support for the BTT SKR V1.4 Turbo board, was chosen as the foundation of the control system. The OY axis, traditionally handling transverse linear translation, was converted into a rotary axis, facilitating the continuous rotation of the cylindrical build drum about the OX axis, while the OX and OZ axes retained their linear nature, carrying out transverse printhead translation and vertical gantry movement, respectively.

Marlin Firmware Adaptation for Polar Coordinates

Applying polar kinematics configuration in Marlin firmware requires enabling the #define POLAR preprocessor directive in the Configuration.h configuration file and defining rotary axes. The POLAR module is by default suited for Cartesian printers with a circular printbed, but its embedded mechanisms can be utilized in the AL geometry. Activating the POLAR module introduces an additional mode interpreting coordinates as rotation angles expressed in degrees, scaling tools dedicated to angular coordinates, and extra safeguards against singularities near the rotational axis.

Unlike linear-motion axes, a rotary axis configured in polar kinematics lacks the requisite of a mechanical home position. Because a rotary axis carries out continuous motion (without mechanical limits), a reference point in the form of limit switches is non-existent. Angular position is a relative variable, and the drum can perform multiple complete revolutions in both directions without restriction. By setting Y_HOME_DIR = 0, the firmware is signaled that the OY axis need not be homed when executing the G28 command; this eliminates the necessity of a physical limit switch for this axis and enables skipping the Y-axis entirely during the system initialization sequence. To facilitate unrestricted drum rotation in both directions, it was necessary to designate the range of movement for the OY axis as practically infinite by assigning extreme values to the software boundaries: Y_MIN_POS = −999 999 and Y_MAX_POS = 999 999.

The TMC2208 drivers were set up for an operating mode making use of UART communication. Configuring the drivers takes place via altering the Configuration_adv.h file, which contains advanced software settings absent in the primary configuration file. This mode permits programmable control over the stepper motors’ operational parameters, which include fine-tuning the reference current restricting the current drawn by motor windings, and direct interfacing with drivers to enable internal measurements and issue diagnosis. The StealthChop operating mode was tapped; this incorporates microstepping virtualization, securing silent operation by neutralizing current oscillations across the coils. Moreover, the StealthChop mode dynamically curates the holding current factor, ultimately unlocking an amplified effective holding torque absent the jeopardy of frying motor windings or the controlling circuitry.

As highlighted in the previous section, the non-standard usage of the HE1 port (second extruder heater port) to manage the heatbreak heatsink cooling fan hinges on resetting output pin assignments in the software configuration. In the vanilla configuration of the BTT SKR V1.4 Turbo board, the HE1 port points to microcontroller pin P2_04 and assumes the role of a heater control output. Transforming this port into a controllable fan output (FAN1) entails factoring corresponding preprocessor directives into the pins_BTT_SKR_V1_4.h blueprint, which anchors hardware pin layouts pertaining to a given mother board.

Operating Parameters Calibration

After compiling and flashing the modified firmware onto the BTT SKR 1.4 Turbo control board, conducting the following calibration protocols is mandatory: verifying and dialing in the correct rotary directionals for stepper motors, calibrating steps per linear displacement unit metrics uniformly along all axes alongside the extruder, and discerning the optimal PID controller settings retaining the requested heater temperature. Linking up with the printer was executed using the Pronterface software tool [21] – a graphical user interface facilitating absolute dominion over the printer setup through transmitting G-code commands and granting real-time hardware status supervision capitalizing on the USB interface.
The foundational steps-per-unit calibration procedure relies on issuing a movement demand encompassing a known threshold, gauging the physical translation attained, and deducing a corrective scalar to compensate for the divergence demarcating physical translation and nominal scope. Harnessing the rotary OY axis calibration drill as a textbook example, within relative positioning bounds (G91), a G1 Y360 F600 macro was executed - manifesting a complete 360° turn paired with a 600°/min angular feed rate ceiling. Subsequent to motion cessation, discrepancies splitting the commanded rotation angle (360°) and the empiric measured span θm, functioned as determinants to trace out the corrective multiplier bounded by the underlying equation:

stepsnew = stepsold ×

360°

θm

,

where θm signifies the real-world measured rotation breadth characterizing the build drum. The readjusted steps count is funneled toward the logic deck via the M92 Y[value] configuration vector and ingrained permanently onto the EEPROM fabric nestled within the driving board’s bounds leveraging the M500 directive. An analogous methodological setup governed the linchpin calibrations tracking linear OX and OZ axes, intertwined with the extruder, wherein the primary test proxy manifested as the linear filament length hauled straight into the extruder body.
The PID controller is tasked with locking in a stable extruder heater temperature bounded by rock-bottom control error waverings. Tuning maneuvers embarked upon vanilla control constants paired with a cartridge heater governed by an NTC 100k thermistor: Kp = 22,2; Ki = 1,08; Kd = 114. Directly following this, the PID autotuning operation sequence ignited off the back of the M303 E0 S210 C5 invocation, compelling the heater block to march through five complete heating and cooling cycles bound for a target core temperature mapping to 210°C. The autotuning algorithm gauges the thermal elasticity of the heating block array through recording warm-up spans, peak overshoot margins, cooldown decay rates, and sweeping thermal ripple amplitudes. Anchored upon harvested metrics, tapping the Ziegler-Nichols optimization stratagem sets out the

Kp, Ki

, and Kd variables.
Upon completing the PID autotuning procedure, the obtained controller parameters Kp = 27,65; Ki = 2,50; Kd = 76, 35 were saved in EEPROM using the M301 P9.25 I0.41 D52.70 command. The principal visible change in parameters was a significant increase in the integral gain, which assisted in the elimination of the steady-state error. The system’s step response exhibits no overshoot or oscillation, and the settling time to reach the target temperature of 210°Cis 2 minutes and 27 seconds.

### 5. MANUFACTURING CAPABILITIES AND APPLICATIONS

Designing with consideration to the specific production process is a natural requirement in manufacturing engineering, applying to every production method used in industry. In FDM technology, the most frequently noticed process limitation is the characteristic layered surface texture of printed elements; material restrictions are also important, as this technology is almost exclusively limited to processing polymer materials.

5.0.1. DfAM in Cartesian 3D printing

The most important criteria for evaluating functional parts made in FDM technology are: mechanical strength, material durability, and dimensional accuracy with faithful reproduction of the designed geometry. The DfAM subsection is dedicated to the most important design issues in the context of Cartesian 3D printers.

Elements manufactured using the FDM method are characterized by high sensitivity to process parameters that control material deposition during production. In a comprehensive literature review [22], researchers identify the process parameters that exert a dominant influence on the mechanical properties of printed parts: build orientation, raster angle, and layer thickness. ”Build orientation in the Z direction proved to be the most dominant factor for tensile strength” – studies conducted by the authors show that flat orientation provides the highest values of tensile strength in the XY plane and bending in the OZ axis. Raster angle, representing the orientation of material fibers relative to the direction of load application, exerts a significant impact on strength – ”raster angles with a higher fraction of the sample oriented along the load axis (e.g., 0°orientation) exhibit improved tensile and compressive strength, while a 90°angle causes significant structural weakening, as the load is transferred through weaker interlayer bonds.” Another important printing parameter is layer thickness, which inversely affects the number of layers and improves the visual print quality. Increasing the number of layers significantly increases production time, and consequently costs, however, its impact on mechanical properties is not unequivocally established: ”thinner layers lead to better bonding between adjacent material lines due to a higher temperature gradient supporting polymer diffusion”, however ”an increased number of layers leads to more cooling and heating cycles, resulting in the accumulation of residual stresses”.

In FDM technology, there is a possibility of manufacturing elements with variable internal infill, which allows for a reduction in printing time and material consumption while maintaining required mechanical properties. Experimental studies [23] show that the main source of the structural strength of printed parts are perimeter parameters (ang. perimeters) and the number of top and bottom layers, not the percentage of the element’s internal infill. In engineering practice, this means that functional parts are usually designed with moderate internal infill of 30 to 40% and an increased number of perimeter walls (4 to 6 lines).

Since material consumption is determined to a much greater extent by the side surface area of the part rather than its volume (resulting from the low percentage of internal infill), increasing the body’s volume does not cause a proportional increase in filament consumption. On the contrary, volume-reducing operations such as cutting smaller bodies out of larger ones, introducing holes or reinforcing ribs, lead to an increase in the total side surface area, and thereby to an increase in the number of outer walls and actual material consumption. Therefore, for components designed for FDM printing, geometries with a larger volume and minimized side surface area are preferred, which is the reverse of the design strategy used in injection molding, where the goal is to minimize material volume by using thin walls and reinforcing ribs with a large surface area.

Ensuring required strength

The weakest link of elements manufactured using the FDM method is the interlayer bond strength. Due to the additive nature of the process, subsequent material layers are deposited successively onto the surface of previous layers, which have already undergone partial solidification and cooling below the polymer’s flow temperature. Under such thermal conditions, polymer chains of the newly applied material layer are unable to form strong intermolecular bonds with the material of the underlying layer. The processes of chain diffusion across the interlayer boundary and their entanglement are significantly limited compared to the monolithic material obtained in injection molding, which achieves isotropic properties. In practice, this means that the tensile strength in the direction perpendicular to the layer planes is several times lower than the strength in the direction parallel to the extruded lines within a single layer. This introduces the necessity of designing the part’s orientation considering the directions of the main operational loads.

The main source of structural strength of FDM parts is not the internal infill (ang. infill), but the number of outer perimeter walls and the top and bottom layers covering the element. Increasing the number of perimeter walls causes a significant increase in bending and tensile strength with a relatively small increase in printing time and material consumption.

A less common case is subjecting FDM elements to compressive stresses. Compressive strength depends mainly on the internal infill. To increase the load-bearing capacity of an element working under compression, it is recommended to increase the internal infill percentage, even to values around 50 to 80%. Mechanical characteristics also depend on the infill pattern. If an element is subjected to compression along one dominant direction, orthogonal patterns are the most effective, such as grid (ang. grid) or triangular (ang. triangular), which provide continuous material columns oriented according to the load direction. In the case of elements loaded with compression from multiple directions, using isotropic patterns, such as cubic (ang. cubic), is recommended. If the priority is to minimize mass and material consumption while maintaining acceptable strength, the optimal choice is the gyroid pattern (ang. gyroid). The gyroid pattern is a three-dimensional minimal surface characterized by a maximum ratio of volume filling to side surface area [24].

Geometric limitations

Another limitation of the FDM process is the inability to deposit material in a space lacking a substrate. Extruded material is in a partially liquid state and requires a substrate on which it can settle and solidify in a controlled manner. Geometric stability requires that every newly applied material layer be supported by the layer below it.

Supported surfaces possess textural artifacts whose amplitude often exceeds the height of a single print layer. These defects prevent precise fitting of elements and require additional finishing machining operations. Furthermore, the process of removing support structures is timeconsuming (usually impossible to automate) and carries the risk of damaging the actual part.

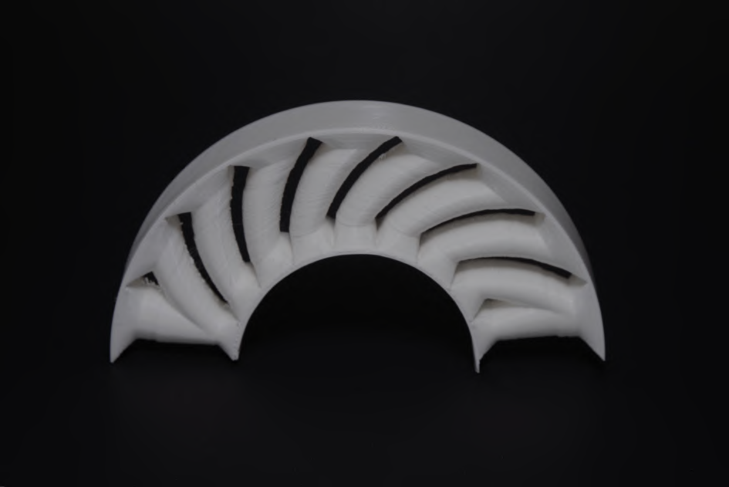
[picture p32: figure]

Figure 5.1: Example of an arch with arcades printed on the implemented cylindrical printer.

Layered surface structure

A characteristic visual artifact of parts manufactured by the FDM method is the visible layered surface structure. Vertical discretization manifests in two forms depending on the surface inclination angle relative to the print plane. Surfaces with a small inclination angle emphasize the staircase effect, in which a smooth surface is approximated by a series of discrete material layers. On surfaces with a large inclination angle, the staircase effect disappears, but the characteristic print layer lines remain visible.

Reducing the thickness of a single layer leads to a decrease in the amplitude of steps on sloped surfaces and a reduction in the visibility of layer lines on vertical surfaces, although it translates to a proportional increase in print time. Moreover, the problem cannot be completely eliminated without a fundamental change in the part’s orientation in the printer’s workspace. Choosing the part’s orientation in such a way that curved planes are oriented vertically relative to the layer plane minimizes the staircase effect.

5.0.2. DfAM in cylindrical 3D printing

Design principles concerning Cartesian 3D printers are largely applicable in cylindrical geometry. The main DfAM changes stem from the radial manufacturing direction, and the designed geometry must also account for the presence of an inner cylinder. The interior can be a cylindrical hole, or a rod constituting an integral part of the printed element.

Fully utilizing the potential of AM requires adapting the slicing strategy and toolpath planning to the specifics of rotational geometry. During the manufacture of a part, for example shaped like a spring, in cylindrical geometry the natural material deposition trajectory is an array of helices wound around the drum’s axis. Such an approach means layer-by-layer application of successive spiral turns in an identical angular orientation, where the raster angle between subsequent layers is 0°. In this case, the extrusion paths are perfectly parallel and lie one on top of the other without any crossover, which results in weakening of the internodal adhesion and delamination of the structure along the layer boundary.

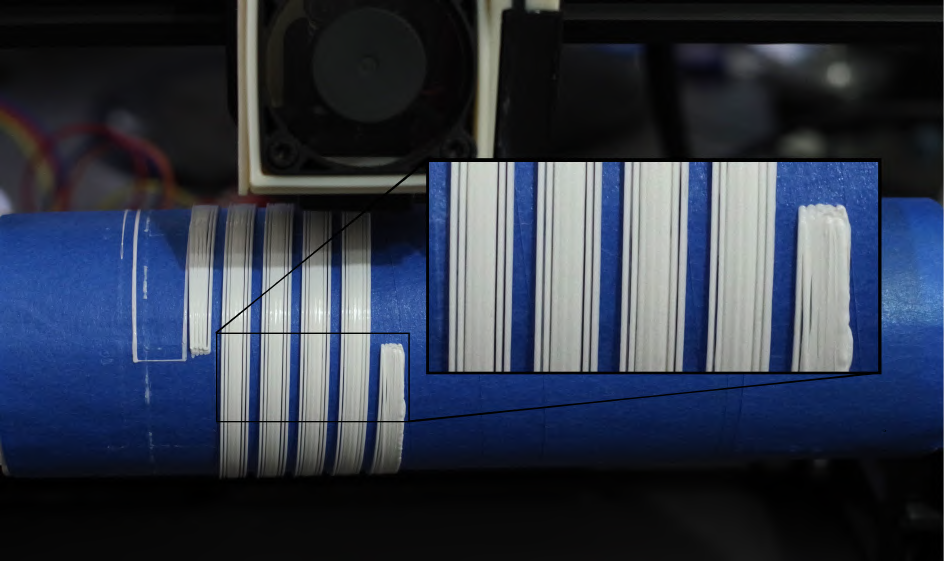
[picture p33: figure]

Figure 5.2: Gaps in the structure of conformal layers visible during the printing of a spring on the implemented cylindrical printer. The printing process did not require the use of support structures.

One way to limit this problem is the appropriate arrangement of successive layers. Suboptimally distributed layers resemble a simple cubic geometric packing of atoms, each subsequent path is applied directly onto the path below, which causes the formation of voids, and in the critical case, gaps visible in Figure 5.2. Using a layer arrangement reminiscent of a face-centered cubic (FCC) lattice allows for filling the interlayer spaces and avoiding layer delamination. Implementing such a solution in practice requires introducing a linear offset of successive layers by a value corresponding to −1/4 of the extrusion path width for odd layers and +1/4 of the path width for even layers. The FCC-style arrangement improves the mutual complementarity of layer geometries and minimizes the formation of interlayer voids 5.3, but it does not eliminate the fundamental problem of a zero raster angle between successive layers.

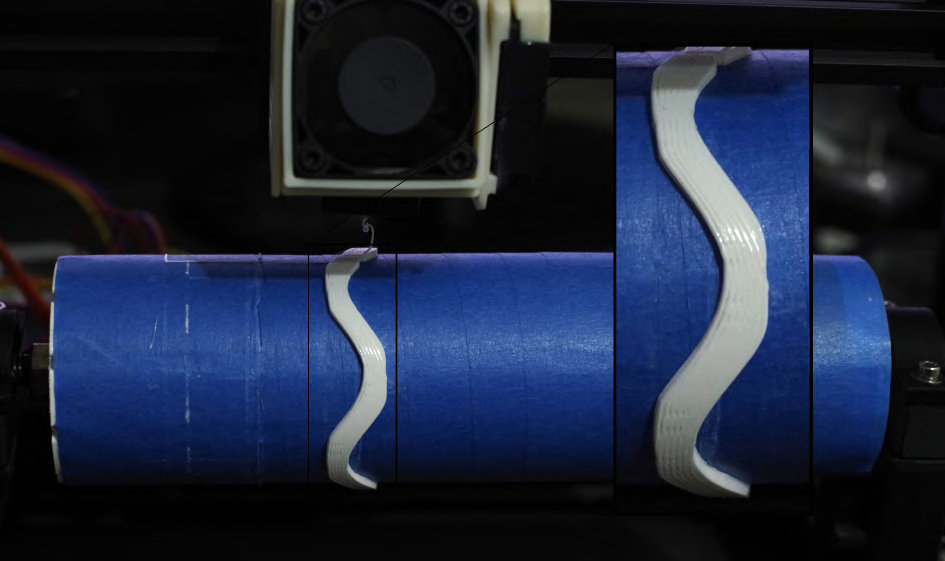
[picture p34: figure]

Figure 5.3: Surface of a bracelet with visible elimination of gaps, thanks to the FCC method.

Achieving the full mechanical strength of the print requires the use of alternating fiber directions, analogous to the technique used in Cartesian 3D printing. Due to the geometry, rotating the helix line will cause the segmentation of the segment into many smaller sections, complicated in mathematical description.

### 5.1. Unique geometric advantages

Traditional turning geometries characterized by axial symmetry are expanded by the range of design capabilities of 3D printers. The additive process allows for the creation of internal structures, non-rotational surfaces, and complex spatial geometries. The AM system is characterized by the ability to manufacture both Cartesian geometries and solids of revolution.

5.1.1. Continuity of rotation

Continuity of rotation is, first and foremost, a necessary condition for the proper manufacture of helical figures; however, it also offers strength advantages for standard elements. The continuity of internal infill paths, braided around the working cylinder, combined with algorithms generating infill patterns that implement the crossover of successive layers, enables achieving material properties close to isotropic properties. Unlike standard Cartesian printing, where a cylindrical figure consists of a series of linear path segments, a cylindrical printer allows material deposition in the form of continuous spirals wound around the rotational axis, eliminating discontinuities associated with transitions between successive segments.

Trajectory continuity can also be used in the ironing operation for solids of revolution. Ironing consists of continuously moving the heated printer nozzle while simultaneously extruding a small amount of material, which leads to smoothing the outer surface of the part. In cylindrical kinematics, it enables obtaining an outer radial surface free from layered artifacts typical of the standard FDM process.

5.1.2. Manufacturing of internal geometries

Subtractive processes, such as turning, rely on removing excess material from a solid raw material. Removing material from the internal areas of a part is physically impossible without first removing the outer layers. Since FDM printers build an element layer by layer from the base, it becomes possible to create arbitrary internal geometries, such as tunnels, channels, internal threads, closed chambers, and other structures inaccessible to machining tools. One type of internal geometry commonly used in FDM printers is the infill pattern. Infill allows the removal of excess material from the print’s interior, which leads to reduced material consumption, faster production times, and decreased part mass.

5.1.3. Avoiding supports

Changing the part’s orientation relative to the build direction is the most effective way to avoid support structures. Some geometries are impossible to print on a Cartesian printer without using supports due to exceeding the allowable overhang angle. The unique geometry of a cylindrical printer allows the use of alternative spatial orientations, which in many cases allow for the complete elimination of support structures.

A commonly cited example in the literature for minimizing the need for supports are propellers. If a segment of a propeller blade profile is characterized by an excessive overhang angle, exceeding the technological capabilities of a Cartesian printer, it is necessary to use support structures under the bottom surfaces of the blades. In a cylindrical printer, the natural orientation

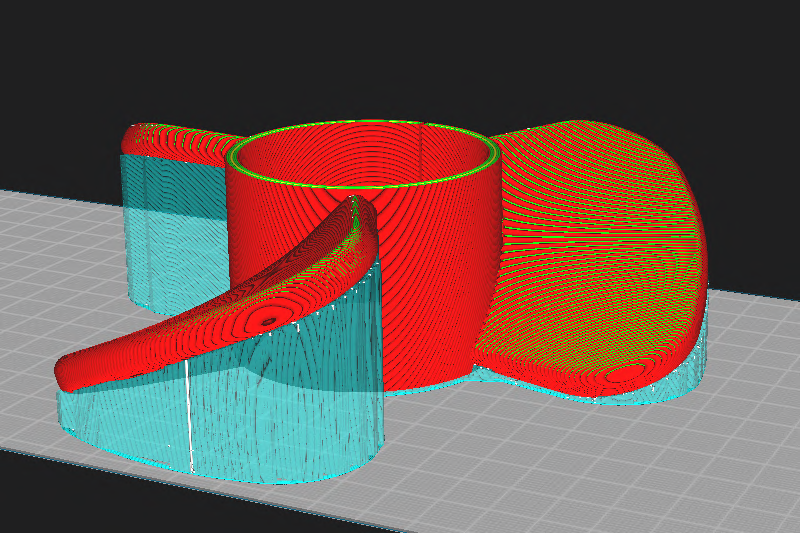
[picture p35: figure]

Figure 5.4: Propeller geometry with supports, Ultimaker Cura screenshot

of the propeller coincides with the rotational axis of the working drum, and the blades are built in a radial direction from the outside.
An analysis of the estimated propeller production time was conducted using Ultimaker Cura software for identical print settings. The geometry of the propeller intended for a Cartesian printer required the generation of support structures (automatic generation of structures for an overhang angle above 45°). The geometry intended for the cylindrical printer did not generate any supports; a detailed comparison is presented in Table 5.1.

Table 5.1: Comparison of estimated print time and percentage distribution of operations

Operation | Cartesian | Cylindrical
| Time | Share [%] | Time | Share [%]
Internal infill | 46 min | 12 | 56 min | 21
Inner walls | 47 min | 12 | 34 min | 13
Outer walls | 30 min | 8 | 25 min | 10
Retractions | 24 min | 6 | 15 min | 6
Top/bottom surfaces | 1h 40min | 25 | 1h 44min | 39
Support structures | 1h 18min | 20 | – | –
Travel moves | 1h 12min | 18 | 29 min | 11
Total time | 6h 42min | 4h 26min

The total production time of the cylindrical geometry is 4 hours and 26 minutes, 2 hours and 16 minutes shorter than the time for Cartesian printing, which is 6 hours and 42 minutes. The main time savings come from the complete elimination of time devoted to manufacturing support structures, which amounted to 1 hour and 18 minutes, or 20% of the total process time. The elimination of structures also caused a significant reduction in the time of travel moves. In cylindrical geometry, travel takes only 40% of the travel move time in Cartesian orientation. Changes in the time of other print operations arise from differences in wall and infill planning due to the different orientation. Reduced print time for wall, infill, and top/bottom surface operations means less material used, so it should not be taken into account for the total time savings. Considering only the time devoted to support structures and additional travel moves, the time savings amounted to 2 hours and 1 minute, representing roughly a 31% print time reduction.

### 6. PATH GENERATION

Manufacturing objects with complex geometry and fully utilizing the specific capabilities of a cylindrical printer requires the application of advanced tool path planning algorithms. In the field of additive manufacturing, there is an extensive ecosystem of specialized slicer software, whose task is to convert a three-dimensional CAD model into a sequence of tool paths. These software applications are limited only to planar solutions, in Cartesian or delta kinematics; in the case of cylindrical printer architecture, a widely available solution does not exist.

### 6.1. Application of Cartesian slicers

The implementation of the Marlin software controlling the cylindrical printer uses the standard Gcode format, differing only in the interpretation of the Y coordinate as a rotation angle instead of a linear displacement. Due to the small differences in G-code, there is a theoretical possibility of using tool paths generated by existing slicers, such as Ultimaker Cura, Orca Slicer, or Prusa Slicer. The application of such a solution is highly desirable because modern software offers advanced algorithms for optimizing the printing process, an extensive set of configuration parameters, and numerous functions dedicated to improving the quality and efficiency of production.

An alternative approach would be the full adaptation of a Cartesian slicer to work in the cylindrical coordinate space, which, due to the complexity of modern solutions, is an undertaking of significant implementation complexity. It would require a thorough modification of the slicing engine algorithms and a systematic adaptation of every program function to the specificity of cylindrical geometry. With the presence of hundreds of specialized algorithms responsible for various parts of the path generation process, such an approach becomes highly impractical.

6.1.1. Limitations and side effects

The first side effect of using Cartesian slicers in cylindrical printing is the distortion of the object’s actual geometry. Direct application of the displacement value in the OY axis expressed in millimeters as a parameter controlling the angular rotation of the cylindrical printer produces geometry curved relative to the curvature of the printer’s drum. The object narrows at the base, and as it moves away from the rotation axis, it widens; the distortion is linearly proportional to the increase in radius. The distortion is dependent on the object’s orientation; the dependence of distortion on orientation is shown in photo 6.1 containing three test prints of the 3D Benchy model [25]. The first model, which has no distortions, was pre-subjected to a corrective transformation and printed on the implemented cylindrical printer. The traditionally printed models have clear geometric distortions depending on the orientation.

Another directly related problem is incorrect material extrusion parameters. Proportionally to the geometric distortion, the actual demand for the amount of extruded filament changes. The nozzle extrudes material evenly around the rotation axis; the volume of the extruded material is distributed over the lateral surface of a cylinder with area A = 2πr L, where L is the length along the cylinder’s axis. Since the circumference 2πr increases linearly with the radius, with a constant volume of extruded material, the surface coverage intensity I(r) decreases inversely proportionally to the radius:
I(r) ∝ 1

r

. | (6.1)

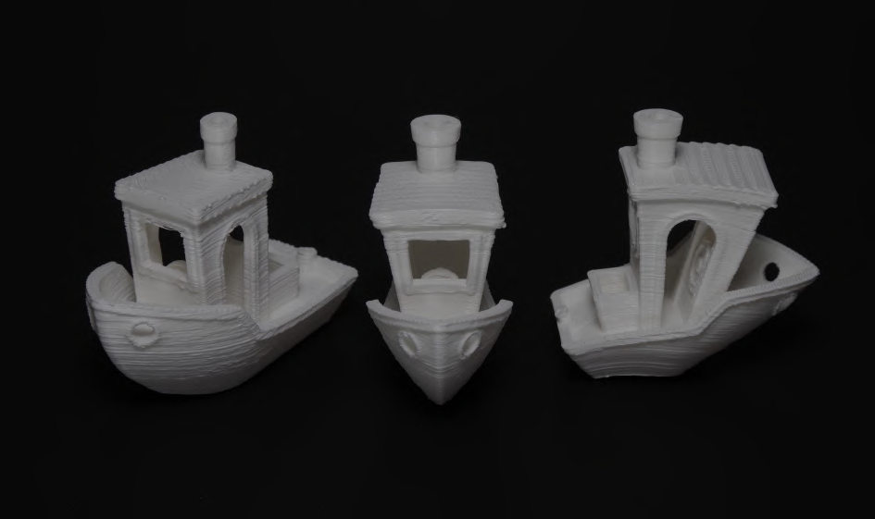
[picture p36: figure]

Figure 6.1: 3D Benchy test print, left print - distortion correction, middle print - distortion relative to the OY axis, right print - relative to the OX axis

The slicer generates commands for extruding the same amount of material regardless of the radius of the trajectory’s curvature. The problem cannot be solved by scaling the extrusion volume using a scaling factor that is a function of the distance from the rotation axis, because only rotational movements around the OY axis are distorted, while linear displacements along the OX axis remain analogous to movements in a Cartesian printer and do not require correction. Furthermore, the realization of some trajectory segments is carried out using simultaneous movement on multiple axes, which means that individual vector components of displacement generate a complex resultant trajectory with variable curvature.
For movement from point (X1, Y1, Z1) to point (X2, Y2, Z2) in the cylindrical system, a Cartesian slicer assumes a rectilinear trajectory in Euclidean space with length:

dk =

√︁
(ΔX)

2 + (ΔY)

2 + (ΔZ)

2
. | (6.2)

Due to the machine’s cylindrical kinematics, the ΔY component is realized as an angular rotation, generating an arc movement with a length dependent on the current radius r = rd + Z. As presented in the section regarding the correction of extrusion parameters (equation 6.11), the actual arc length is:

s = r · |ΔY | · π
180
, | (6.3)

where the radius r is constant within a single layer. The actual trajectory length in cylindrical space is therefore the vector sum of linear and arc displacements (equation 6.12):

dc =

√︁
(ΔX)

2 + s

2 + (ΔZ)

2
. | (6.4)

The ratio of these lengths dc/dk is not constant and varies as a function of the radius and the proportion of displacement components. For purely rotational movement (ΔX = ΔZ = 0), the ratio is r · π/180, while for purely linear movement along the OX axis, the ratio is equal to one. For mixed trajectories, the correction factor takes intermediate values, which makes it impossible to apply a global, constant scaling factor for extrusion.
The last limitation is the lack of topological continuity at the transition from 0 to 360 degrees. Modern software implementations for Cartesian printers operate in Euclidean space, where the transition between coordinates X and X +ΔX requires visiting all intermediate values in accordance with the property of function continuity. The cylindrical projection of a cylinder onto the XY plane requires "cutting the cylinder," which results in the loss of topological continuity. Using the full surface of the cylinder during path generation is still possible, however, software algorithms do not take into account the possibility of a continuous transition through the 0°/360° boundary when generating tool paths.
The failure to account for continuity causes problems when manufacturing geometry with a spiral topology, e.g., helical springs, and also negatively affects the mechanical strength of manufactured parts. For example, for the shape of a torus in the cylindrical coordinate space, which after transformation to Cartesian space (by cutting and unfolding onto a flat surface), can be represented as a cylinder (ignoring the distortions caused by the varying distance from the axis of rotation), the slicer algorithm generates circle-shaped walls at the bases of the cylinder. This cylinder has two such bases at coordinates 0° and 360°, treated as separate elements. Production of such geometry on a cylindrical printer results in a raster angle at the coordinate transition equal to 0 degrees, which means arranging the extrusion lines perpendicular to each other and abandoning the interlacing of polymer bundles between layers. As discussed in the previous chapter, proper bundle interlacing is one of the key factors determining the mechanical strength of parts manufactured using the FDM method.
6.1.2. Solutions to limitations

Limitations resulting from geometric distortions are not dependent on how the slicer works, which enables the development of algorithms to compensate for these distortions within the software implementation. Problems related to topological continuity would require interference in the algorithmic structure of slicers, which is beyond the scope of the project. Nevertheless, the solution relying on geometric distortion compensation combined with limited continuity support preserves a significant part of the theoretical functionality of the cylindrical 3D printer.

Correction of geometric curvature

The geometric curvature correction algorithm performs a transformation of the CAD model in a way that compensates for the distortions occurring during the cylindrical printing process. This transformation can be described mathematically as follows:
For a pair of points defined in the Cartesian spatial coordinate system as (x1, y1, z1) and (x2, y2, z2) with relative position (Δx, Δy, Δz), there is a corresponding pair of points (x3, y3, z3) and (x4, y4, z4), which, after a pair of preliminary transformation operations and a transformation to the cylindrical coordinate space, has an identical relative position (Δx, Δy, Δz). The preliminary transformation operation performs the inverse transformation to the unfolding transformation to cylindrical geometry.
For a single input point (xi
, yi

, zi) in the Cartesian system, the radius from the rotation axis is expressed as:

ri =

√︃
y

2
i

+ z

2
i
. | (6.5)

The angle in the polar system is calculated using the two-argument arctangent function:

θi = arctan 2(yi

, zi). | (6.6)

After taking into account the cutting position on the cylinder, defined as angle θc, the transformed angle is expressed by the formula:

θ

′
i = θi − θc, | (6.7)

where the value is then normalized to the range [0°, 360°). The height above the surface of the drum with radius rd is:

zi,cart = ri − rd. | (6.8)

The coordinates of the point transformed for slicing in the Cartesian program take the form:

xi,cart = xi

yi,cart = θ

′
i

zi,cart = ri − rd

. | (6.9)

The ycart coordinate represents the angle in degrees, which is then handled by the slicer as a linear dimension in millimeters. During printing, this value is interpreted by the software controlling the cylindrical printer as the rotation angle, which results in the reversal of the distortion and the reproduction of the original geometry.
Due to the non-linearity of the transformation, the amplitude of which increases with the radius, the model edges require subdivision in order to maintain geometric accuracy. An edge is subdivided if any of the following conditions are met:
- linear distance √︁
(Δx)

2 + (Δz)

2 > Lmax, where Lmax = 2 mm,

- change in arc length |Δyarc| > Lmax,
- change in angle |Δθ| > θmax, where θmax = 5°.

The subdivision process is carried out recursively by dividing each triangle into four smaller ones by adding midpoints on each edge until all accuracy criteria are met.

Correction of extrusion parameters

The transformation of the geometry to the Cartesian coordinate system introduces a discrepancy between the actual length of the trajectory in cylindrical space and the length assumed by the Cartesian slicer, which subsequently generates incorrect extrusion values. The extrusion parameter correction algorithm compensates for this discrepancy by recalculating the extrusion values in the generated G-code.
For a movement between two points (X1, Y1, Z1) and (X2, Y2, Z2), where Y represents the angle in degrees, the Cartesian slicer calculates the distance as:

dk =

√︁
(ΔX)

2 + (ΔY)

2 + (ΔZ)

2
, | (6.10)

treating ΔY as a linear change of coordinate in millimeters.
The actual distance in cylindrical space requires considering the curvature radius. For an angle change ΔY expressed in degrees, the arc length on radius r is:
s = r · |ΔY | · π
180
, | (6.11)

where the radius r = rd + Z is constant within a single layer (movement within the layer maintains a constant Z value). The actual trajectory length in cylindrical space is given by the formula:

dc =

√︁
(ΔX)

2 + s

2 + (ΔZ)

2
, | (6.12)

The amount of extruded material should be proportional to the actual length of the trajectory. The slicer computes the extrusion value Eo based on distance dk, so the extrusion coefficient per unit length is:

kE =

Eo

dk

. | (6.13)

The corrected extrusion value for the actual cylindrical distance is calculated as:

Ek = kE · dc = Eo ·

dc

dk

. | (6.14)

The algorithm parses the G-code file line by line, identifying movement commands G0 and G1 that contain an extrusion parameter E that is not a retraction extrusion component. For each such command, it computes the correction factor dc/dk and substitutes the original value of parameter E with the corrected value Ek.

6.1.3. Description of design using the proposed method

The process of designing parts intended for manufacturing on a cylindrical printer using Cartesian slicers consists of the following stages:

Design in CAD software. The designer creates a three-dimensional model in the target dimensions, designing the geometry around the cylinder’s axis of rotation. The model represents the actual shape the object is supposed to have after printing on a cylindrical printer.

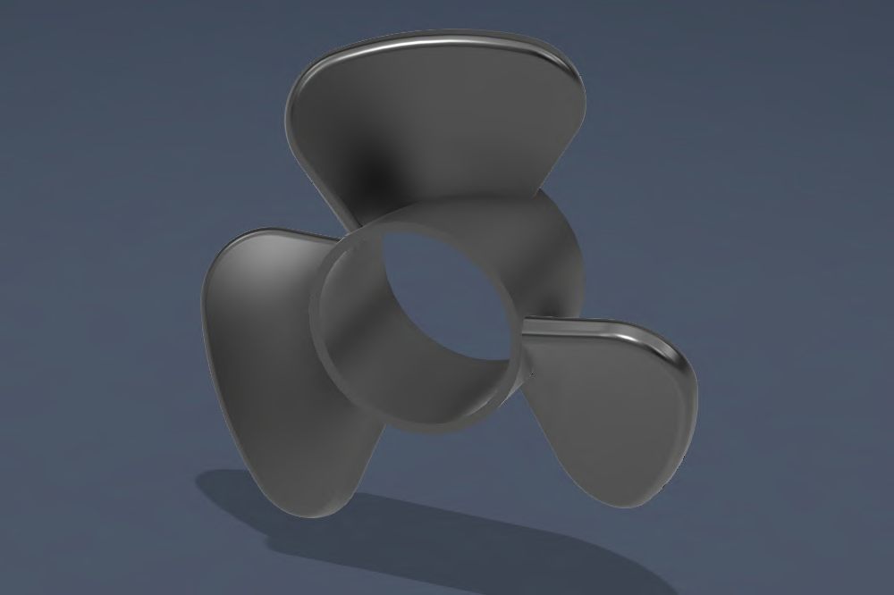
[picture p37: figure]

Figure 6.2: Propeller CAD design in Autodesk Fusion 360

Geometric conversion. The model is exported to STL format, and then subjected to transformation using the Python script cylindrical_to_cartesian.py. This process performs the inverse unfolding of the cylindrical geometry.

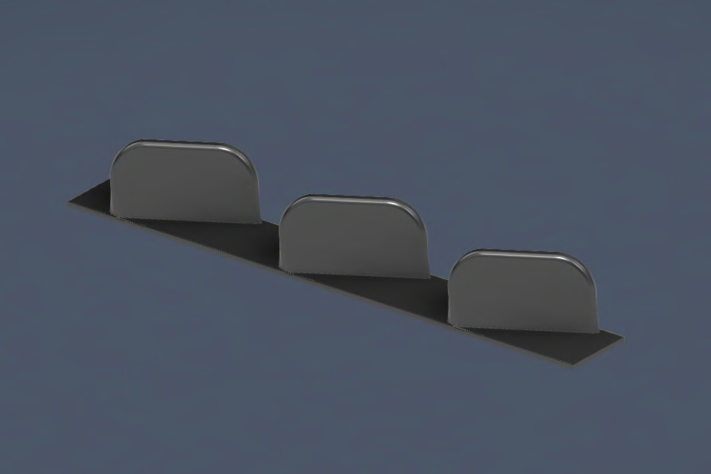
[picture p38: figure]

Figure 6.3: Propeller geometry after inverse cylindrical transformation

Tool path generation. The transformed model is imported into a slicer (e.g., Cura), where the standard procedure of generating tool paths is performed using the software’s full functionality. It is necessary to create a profile representing the available dimensions of the build plate after unfolding the cylinder.

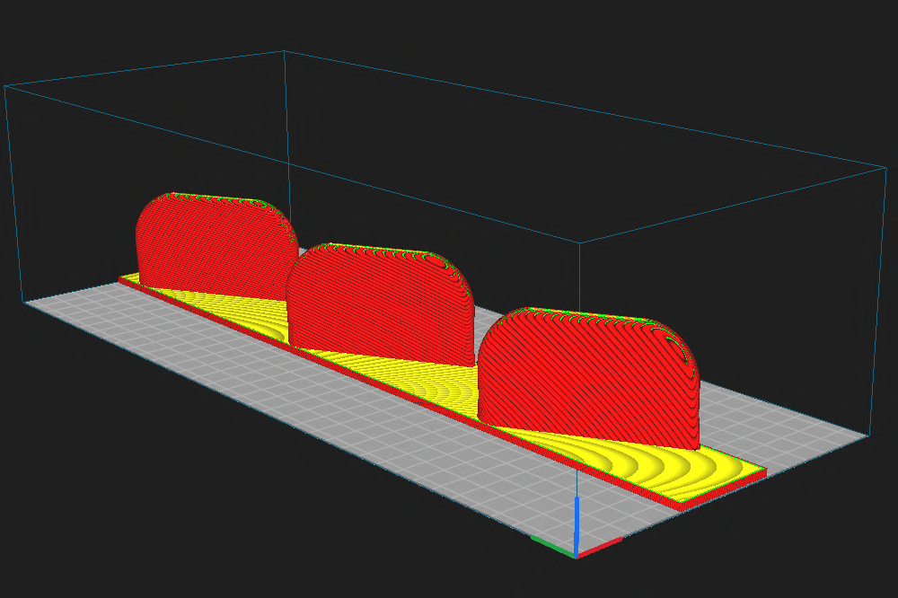
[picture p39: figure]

Figure 6.4: Path generation in Ultimaker Cura

Correction of extrusion parameters. The generated G-code file is processed using the Python script recalculate_extrusion.py, which recalculates the extrusion values according to the actual trajectory length in cylindrical space. After this operation, the G-code is ready for execution on the cylindrical printer.

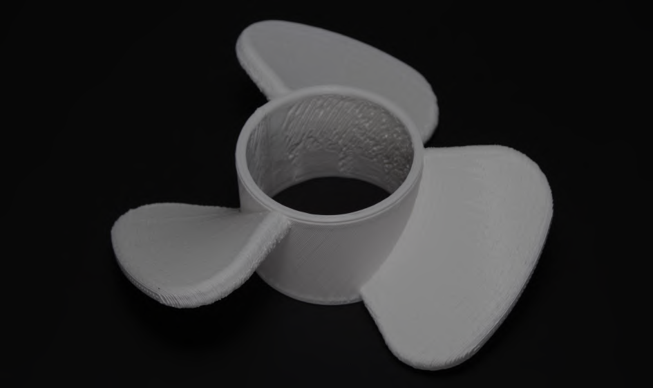
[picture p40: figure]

Figure 6.5: Photo of a propeller printed using the implemented cylindrical 3D printer

6.1.4. Conclusions from the application of Cartesian slicers

For geometries whose angular span falls within a range of less than a full rotation (< 360°), the use of a standard Cartesian slicer in conjunction with the presented method of geometry transformation and dimensional correction is a solution that achieves capabilities close to the state of the art in path generation for Cartesian printers. Geometry correction ensures the dimensional and geometric fidelity of the manufactured objects.

The presented approach also has the positive side effect of creating non-planar layers when printing Cartesian geometries. The object’s layers have a cylindrical profile, and the surface of a cylindrical layer is larger than the corresponding surface of flat layers found in prints from Cartesian printers. The larger layer surface leads to improved interlayer adhesion, while its curved profile enables a more effective stress distribution [26]. These effects can contribute to increasing the mechanical strength of prints, similar to the effects that can be achieved on 4-axis non-planar printers.

For geometries with continuous topology, where it is desirable to utilize continuity at the 0°/360° transition to fully exploit the capabilities of a cylindrical printer, the current state of algorithm development does not offer a practical solution. Combining the full functionality of a modern slicer with the advantages resulting from the topological continuity of prints on a cylindrical printer is not possible to achieve using the presented method and remains unattainable until the development of a full adaptation of a cylindrical geometry slicer.
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

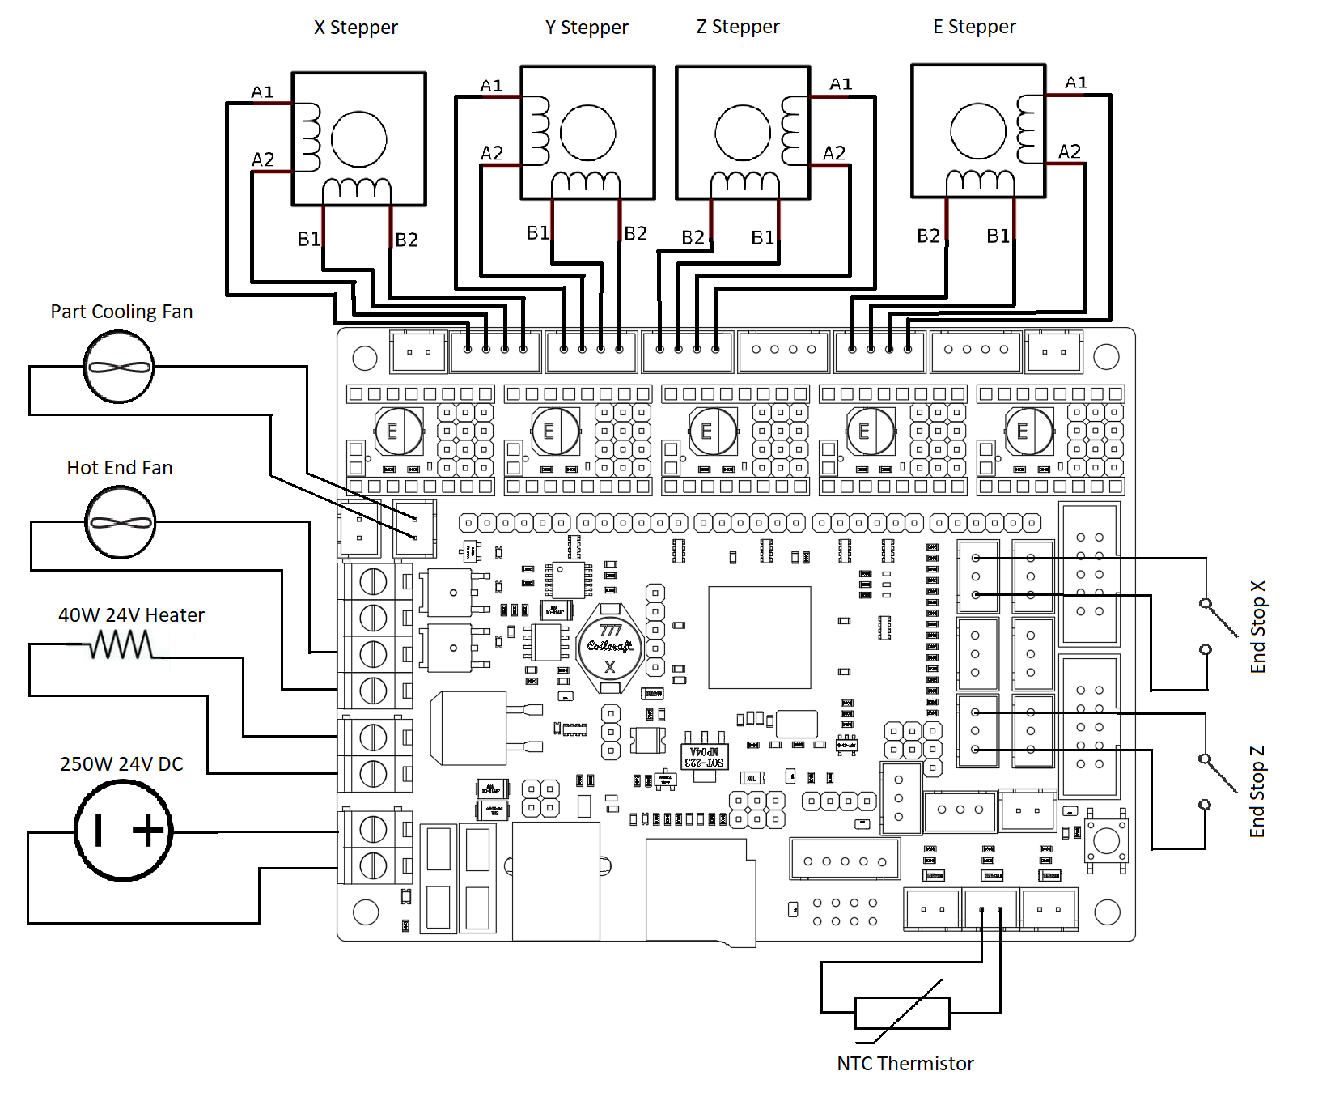
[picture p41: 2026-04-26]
docs/Wiring BTT SKR V1.4.png

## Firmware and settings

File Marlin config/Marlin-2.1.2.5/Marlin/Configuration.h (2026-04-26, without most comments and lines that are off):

#pragma once
#define CONFIGURATION_H_VERSION 02010205
#define STRING_CONFIG_H_AUTHOR "(Grzegorz Lange 25.11.2025)" // Who made the changes.
#define SHOW_BOOTSCREEN
  #define MOTHERBOARD BOARD_BTT_SKR_V1_4_TURBO
#define SERIAL_PORT -1
#define BAUDRATE 250000
#define SERIAL_PORT_2 0
#define BAUDRATE_2 250000   // :[2400, 9600, 19200, 38400, 57600, 115200, 250000, 500000, 1000000] Enable to override BAUDRATE
#define X_DRIVER_TYPE  TMC2208
#define Y_DRIVER_TYPE  TMC2208
#define Z_DRIVER_TYPE  TMC2208
#define E0_DRIVER_TYPE TMC2208
#define EXTRUDERS 1
#define DEFAULT_NOMINAL_FILAMENT_DIA 1.75
#define TEMP_SENSOR_0 1  // ender 3v2 therimistor
#define TEMP_SENSOR_1 0
#define TEMP_SENSOR_2 0
#define TEMP_SENSOR_3 0
#define TEMP_SENSOR_4 0
#define TEMP_SENSOR_5 0
#define TEMP_SENSOR_6 0
#define TEMP_SENSOR_7 0
#define TEMP_SENSOR_BED 0  // No heated bed for cylindrical printer
#define TEMP_SENSOR_PROBE 0
#define TEMP_SENSOR_CHAMBER 0
#define TEMP_SENSOR_COOLER 0
#define TEMP_SENSOR_BOARD 0
#define TEMP_SENSOR_REDUNDANT 0
#define DUMMY_THERMISTOR_998_VALUE  25
#define DUMMY_THERMISTOR_999_VALUE 100
#if TEMP_SENSOR_IS_MAX_TC(0)
  #define MAX31865_SENSOR_OHMS_0      100 // (Ω) Typically 100 or 1000 (PT100 or PT1000)
  #define MAX31865_CALIBRATION_OHMS_0 430 // (Ω) Typically 430 for Adafruit PT100; 4300 for Adafruit PT1000
#endif
#if TEMP_SENSOR_IS_MAX_TC(1)
  #define MAX31865_SENSOR_OHMS_1      100
  #define MAX31865_CALIBRATION_OHMS_1 430
#endif
#if TEMP_SENSOR_IS_MAX_TC(2)
  #define MAX31865_SENSOR_OHMS_2      100
  #define MAX31865_CALIBRATION_OHMS_2 430
#endif
#if HAS_E_TEMP_SENSOR
  #define TEMP_RESIDENCY_TIME         10  // (seconds) Time to wait for hotend to "settle" in M109
  #define TEMP_WINDOW                  1  // (°C) Temperature proximity for the "temperature reached" timer
  #define TEMP_HYSTERESIS              3  // (°C) Temperature proximity considered "close enough" to the target
#endif
#if TEMP_SENSOR_BED
  #define TEMP_BED_RESIDENCY_TIME     10  // (seconds) Time to wait for bed to "settle" in M190
  #define TEMP_BED_WINDOW              1  // (°C) Temperature proximity for the "temperature reached" timer
  #define TEMP_BED_HYSTERESIS          3  // (°C) Temperature proximity considered "close enough" to the target
#endif
#if TEMP_SENSOR_CHAMBER
  #define TEMP_CHAMBER_RESIDENCY_TIME 10  // (seconds) Time to wait for chamber to "settle" in M191
  #define TEMP_CHAMBER_WINDOW          1  // (°C) Temperature proximity for the "temperature reached" timer
  #define TEMP_CHAMBER_HYSTERESIS      3  // (°C) Temperature proximity considered "close enough" to the target
#endif
#if TEMP_SENSOR_REDUNDANT
  #define TEMP_SENSOR_REDUNDANT_SOURCE    E1  // The sensor that will provide the redundant reading.
  #define TEMP_SENSOR_REDUNDANT_TARGET    E0  // The sensor that we are providing a redundant reading for.
  #define TEMP_SENSOR_REDUNDANT_MAX_DIFF  10  // (°C) Temperature difference that will trigger a print abort.
#endif
#define HEATER_0_MINTEMP   5
#define HEATER_1_MINTEMP   5
#define HEATER_2_MINTEMP   5
#define HEATER_3_MINTEMP   5
#define HEATER_4_MINTEMP   5
#define HEATER_5_MINTEMP   5
#define HEATER_6_MINTEMP   5
#define HEATER_7_MINTEMP   5
#define BED_MINTEMP        5
#define CHAMBER_MINTEMP    5
#define HEATER_0_MAXTEMP 275
#define HEATER_1_MAXTEMP 275
#define HEATER_2_MAXTEMP 275
#define HEATER_3_MAXTEMP 275
#define HEATER_4_MAXTEMP 275
#define HEATER_5_MAXTEMP 275
#define HEATER_6_MAXTEMP 275
#define HEATER_7_MAXTEMP 275
#define BED_MAXTEMP      150
#define CHAMBER_MAXTEMP  60
#define HOTEND_OVERSHOOT 15   // (°C) Forbid temperatures over MAXTEMP - OVERSHOOT
#define BED_OVERSHOOT    10   // (°C) Forbid temperatures over MAXTEMP - OVERSHOOT
#define COOLER_OVERSHOOT  2   // (°C) Forbid temperatures closer than OVERSHOOT
#define PIDTEMP           // See the PID Tuning Guide at https://reprap.org/wiki/PID_Tuning
#define PID_MAX  255      // Limit hotend current while PID is active (see PID_FUNCTIONAL_RANGE below); 255=full current
#define PID_K1     0.95   // Smoothing factor within any PID loop
    #define DEFAULT_Kp  22.20
    #define DEFAULT_Ki   1.08
    #define DEFAULT_Kd 114.00
#define MAX_BED_POWER 255 // limits duty cycle to bed; 255=full current
#define MAX_CHAMBER_POWER 255 // limits duty cycle to chamber heater; 255=full current
  #define PID_FUNCTIONAL_RANGE 10 // If the temperature difference between the target temperature and the actual temperature
#define PREVENT_COLD_EXTRUSION
#define EXTRUDE_MINTEMP 170
#define PREVENT_LENGTHY_EXTRUDE
#define EXTRUDE_MAXLENGTH 200
#define THERMAL_PROTECTION_HOTENDS // Enable thermal protection for all extruders
#define THERMAL_PROTECTION_BED     // Enable thermal protection for the heated bed
#define THERMAL_PROTECTION_CHAMBER // Enable thermal protection for the heated chamber
#define THERMAL_PROTECTION_COOLER  // Enable thermal protection for the laser cooling
#define POLAR
  #define DEFAULT_SEGMENTS_PER_SECOND 180   // If movement is choppy try lowering this value
  #define PRINTABLE_RADIUS 153.0f           // (mm) Maximum travel of X axis - matches X_BED_SIZE
  #define POLAR_FAST_RADIUS 3.0f            // (mm)
  #define POLAR_CENTER_OFFSET 0.0f          // (mm)
  #define FEEDRATE_SCALING                  // Convert XY feedrate from mm/s to degrees/s on the fly
#define USE_XMIN_PLUG   // X-axis (left/right) endstop for homing
#define USE_ZMIN_PLUG   // Z-axis (up/down) endstop for homing
#define ENDSTOPPULLUPS
#define X_MIN_ENDSTOP_INVERTING true  // Inverted for wiring
#define Y_MIN_ENDSTOP_INVERTING false // Set to true to invert the logic of the endstop.
#define Z_MIN_ENDSTOP_INVERTING true  // Inverted for wiring
#define I_MIN_ENDSTOP_INVERTING false // Set to true to invert the logic of the endstop.
#define J_MIN_ENDSTOP_INVERTING false // Set to true to invert the logic of the endstop.
#define K_MIN_ENDSTOP_INVERTING false // Set to true to invert the logic of the endstop.
#define U_MIN_ENDSTOP_INVERTING false // Set to true to invert the logic of the endstop.
#define V_MIN_ENDSTOP_INVERTING false // Set to true to invert the logic of the endstop.
#define W_MIN_ENDSTOP_INVERTING false // Set to true to invert the logic of the endstop.
#define X_MAX_ENDSTOP_INVERTING false // Set to true to invert the logic of the endstop.
#define Y_MAX_ENDSTOP_INVERTING false // Set to true to invert the logic of the endstop.
#define Z_MAX_ENDSTOP_INVERTING false // Set to true to invert the logic of the endstop.
#define I_MAX_ENDSTOP_INVERTING false // Set to true to invert the logic of the endstop.
#define J_MAX_ENDSTOP_INVERTING false // Set to true to invert the logic of the endstop.
#define K_MAX_ENDSTOP_INVERTING false // Set to true to invert the logic of the endstop.
#define U_MAX_ENDSTOP_INVERTING false // Set to true to invert the logic of the endstop.
#define V_MAX_ENDSTOP_INVERTING false // Set to true to invert the logic of the endstop.
#define W_MAX_ENDSTOP_INVERTING false // Set to true to invert the logic of the endstop.
#define Z_MIN_PROBE_ENDSTOP_INVERTING false // Set to true to invert the logic of the probe.
#define DEFAULT_AXIS_STEPS_PER_UNIT   { 40, 71.50, 200, 72 }
#define DEFAULT_MAX_FEEDRATE          { 300, 300, 5, 25 }
#define DEFAULT_MAX_ACCELERATION      { 3000, 3000, 100, 10000 }
#define DEFAULT_ACCELERATION          3000    // X, Y, Z and E acceleration for printing moves
#define DEFAULT_RETRACT_ACCELERATION  3000    // E acceleration for retracts
#define DEFAULT_TRAVEL_ACCELERATION   3000    // X, Y, Z acceleration for travel (non printing) moves
#define DEFAULT_EJERK    5.0  // May be used by Linear Advance
  #define JUNCTION_DEVIATION_MM 0.013 // (mm) Distance from real junction edge
  #define JD_HANDLE_SMALL_SEGMENTS    // Use curvature estimation instead of just the junction angle
#define Z_MIN_PROBE_USES_Z_MIN_ENDSTOP_PIN
#define NOZZLE_TO_PROBE_OFFSET { 10, 10, 0 }
#define PROBING_MARGIN 10
#define XY_PROBE_FEEDRATE (133*60)
#define Z_PROBE_FEEDRATE_FAST (4*60)
#define Z_PROBE_FEEDRATE_SLOW (Z_PROBE_FEEDRATE_FAST / 2)
#define Z_CLEARANCE_DEPLOY_PROBE   10 // (mm) Z Clearance for Deploy/Stow
#define Z_CLEARANCE_BETWEEN_PROBES  5 // (mm) Z Clearance between probe points
#define Z_CLEARANCE_MULTI_PROBE     5 // (mm) Z Clearance between multiple probes
#define Z_PROBE_LOW_POINT          -2 // (mm) Farthest distance below the trigger-point to go before stopping
#define Z_PROBE_OFFSET_RANGE_MIN -20
#define Z_PROBE_OFFSET_RANGE_MAX 20
#define X_ENABLE_ON 0
#define Y_ENABLE_ON 0
#define Z_ENABLE_ON 0
#define E_ENABLE_ON 0 // For all extruders
#define DISABLE_OTHER_EXTRUDERS   // Keep only the active extruder enabled
#define INVERT_X_DIR true   // Inverted for wiring
#define INVERT_Y_DIR true
#define INVERT_Z_DIR false
#define INVERT_E0_DIR true
#define INVERT_E1_DIR false
#define INVERT_E2_DIR false
#define INVERT_E3_DIR false
#define INVERT_E4_DIR false
#define INVERT_E5_DIR false
#define INVERT_E6_DIR false
#define INVERT_E7_DIR false
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

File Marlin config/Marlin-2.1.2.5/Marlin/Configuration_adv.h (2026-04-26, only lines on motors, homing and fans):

#define E0_AUTO_FAN_PIN P2_04
#define E1_AUTO_FAN_PIN -1
#define E2_AUTO_FAN_PIN -1
#define E3_AUTO_FAN_PIN -1
#define E4_AUTO_FAN_PIN -1
#define E5_AUTO_FAN_PIN -1
#define E6_AUTO_FAN_PIN -1
#define E7_AUTO_FAN_PIN -1
#define CHAMBER_AUTO_FAN_PIN -1
#define COOLER_AUTO_FAN_PIN -1
#define HOMING_BUMP_MM      { 5, 5, 2 }       // (linear=mm, rotational=°) Backoff from endstops after first bump
#define HOMING_BUMP_DIVISOR { 2, 2, 4 }       // Re-Bump Speed Divisor (Divides the Homing Feedrate)
#define MICROSTEP_MODES { 16, 16, 16, 16, 16, 16 } // [1,2,4,8,16]
    #define X_CURRENT       800        // (mA) RMS current. Multiply by 1.414 for peak current.
    #define X_CURRENT_HOME  X_CURRENT  // (mA) RMS current for homing. (Typically lower than *_CURRENT.)
    #define X_MICROSTEPS     16        // 0..256
    #define Y_CURRENT       800
    #define Y_CURRENT_HOME  Y_CURRENT
    #define Y_MICROSTEPS     16
    #define Z_CURRENT       800
    #define Z_CURRENT_HOME  Z_CURRENT
    #define Z_MICROSTEPS     16
    #define E0_CURRENT      800
    #define E0_MICROSTEPS    16
    #define CURRENT_STEP_DOWN     50  // [mA]
    #define REPORT_CURRENT_CHANGE
  #define X_HYBRID_THRESHOLD     100  // [mm/s]
  #define X2_HYBRID_THRESHOLD    100
  #define Y_HYBRID_THRESHOLD     100
  #define Y2_HYBRID_THRESHOLD    100
  #define Z_HYBRID_THRESHOLD       3
  #define Z2_HYBRID_THRESHOLD      3
  #define Z3_HYBRID_THRESHOLD      3
  #define Z4_HYBRID_THRESHOLD      3
  #define I_HYBRID_THRESHOLD       3  // [linear=mm/s, rotational=°/s]
  #define J_HYBRID_THRESHOLD       3  // [linear=mm/s, rotational=°/s]
  #define K_HYBRID_THRESHOLD       3  // [linear=mm/s, rotational=°/s]
  #define U_HYBRID_THRESHOLD       3  // [mm/s]
  #define V_HYBRID_THRESHOLD       3
  #define W_HYBRID_THRESHOLD       3
  #define E0_HYBRID_THRESHOLD     30
  #define E1_HYBRID_THRESHOLD     30
  #define E2_HYBRID_THRESHOLD     30
  #define E3_HYBRID_THRESHOLD     30
  #define E4_HYBRID_THRESHOLD     30
  #define E5_HYBRID_THRESHOLD     30
  #define E6_HYBRID_THRESHOLD     30
  #define E7_HYBRID_THRESHOLD     30

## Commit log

2026-04-26 Cura Slicer to cylindrical conversion
    [3DBenchyCut_flattened_decimated.stl, Custom+Cylindrical.global.cfg, custom_extruder_1+%233.extruder.cfg]
2026-04-26 Marlin Config
    [Configuration.h, Configuration_adv.h]

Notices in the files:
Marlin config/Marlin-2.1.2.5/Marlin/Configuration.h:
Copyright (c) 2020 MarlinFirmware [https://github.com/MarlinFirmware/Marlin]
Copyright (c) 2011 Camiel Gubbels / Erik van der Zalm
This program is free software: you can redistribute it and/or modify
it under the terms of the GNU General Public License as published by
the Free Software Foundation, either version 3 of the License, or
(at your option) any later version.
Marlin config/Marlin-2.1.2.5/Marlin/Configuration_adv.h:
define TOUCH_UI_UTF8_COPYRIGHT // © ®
